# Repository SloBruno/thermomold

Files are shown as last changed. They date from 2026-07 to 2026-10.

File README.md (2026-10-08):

# ThermoMold

Monitoramento e controle remoto de um circuito de refrigeração de molde. O projeto combina um **ESP32 com sensores físicos**, um **backend Node.js no Render** e um **dashboard React publicado no GitHub Pages**. Também preserva o simulador didático de circuito de refrigeração já existente.

> **Estado atual:** o código suporta dois termopares MAX6675, nível AJ-SR04M, vazão ZJ-S201, duas bombas via relé HW-383 e telemetria em tempo quase real. A validação física do ZJ-S201 e dos relés com as bombas ainda deve ser feita em bancada antes de uso contínuo.

- Dashboard: <https://slobruno.github.io/thermomold/>
- Sensores físicos: <https://slobruno.github.io/thermomold/#/sensor-real>
- Calibração: <https://slobruno.github.io/thermomold/#/calibracao>
- Controle de bombas: <https://slobruno.github.io/thermomold/#/bombas>
- API: <https://thermomold.onrender.com/api/telemetry>

## Índice

- [Objetivo e escopo](#objetivo-e-escopo)
- [Arquitetura](#arquitetura)
- [Funcionalidades](#funcionalidades)
- [Hardware e ligações](#hardware-e-ligações)
- [Firmware ESP32](#firmware-esp32)
- [Backend e API](#backend-e-api)
- [Frontend](#frontend)
- [Implantação](#implantação)
- [Desenvolvimento local](#desenvolvimento-local)
- [Segurança e limites atuais](#segurança-e-limites-atuais)
- [Validação de bancada](#validação-de-bancada)
- [Próximas etapas](#próximas-etapas)

## Objetivo e escopo

O ThermoMold é um sistema para acompanhar um pequeno circuito hidráulico de refrigeração e permitir o acionamento remoto de duas bombas.

### Incluído no escopo atual

- Medição de temperatura em dois pontos com dois módulos MAX6675 e termopares tipo K.
- Calibração pública de dois pontos, independente para cada MAX6675, com revisão persistente.
- Medição de distância/nível com AJ-SR04M.
- Medição de vazão instantânea e volume acumulado com ZJ-S201.
- Telemetria do ESP32 para a internet por Wi-Fi e HTTPS.
- Dashboard web com atualização periódica e atualização em tempo real por Socket.IO.
- Comando manual de liga/desliga para duas bombas, por relé duplo HW-383.
- Estado seguro: bombas desligadas ao iniciar o ESP32, ao perder Wi-Fi ou ao perder comunicação válida com o backend.
- Portal de provisionamento Wi-Fi e armazenamento persistente da configuração do dispositivo no ESP32.
- Simulador de refrigeração e biblioteca de moldes, independentes da telemetria física.
- Esquema elétrico editável no KiCad, PDF e instruções de montagem em texto.

### Fora do escopo atual

- Controle de velocidade/intensidade das bombas. O HW-383 é relé mecânico e só permite liga/desliga; PWM exige driver MOSFET apropriado.
- Histórico persistente de medições. O backend mantém somente a última leitura em memória.
- Autenticação de operadores para o controle de bombas. O controle foi configurado como público nesta fase.
- Atualização OTA do firmware.
- Calibração física final do fator de pulsos do ZJ-S201.
- Proteções automáticas por nível baixo, falta de vazão, temperatura ou tempo máximo de bomba ligada.

## Arquitetura

```text
                         ┌───────────────────────────┐
                         │ GitHub Pages               │
                         │ React + Vite               │
                         │ Dashboard / Sensores /     │
                         │ Controle de Bombas         │
                         └─────────────┬─────────────┘
                                       │ HTTPS + Socket.IO
                                       │
                         ┌─────────────▼─────────────┐
                         │ Render                     │
                         │ Express + Socket.IO        │
                         │ - valida telemetria        │
                         │ - mantém última leitura    │
                         │ - mantém comando desejado  │
                         └─────────────┬─────────────┘
                                       │ HTTPS POST /api/telemetry
                                       │ resposta inclui comando das bombas
                                       │
                         ┌─────────────▼─────────────┐
                         │ ESP32                      │
                         │ Wi-Fi + LittleFS           │
                         │ Sensores + relés           │
                         └───┬────┬────┬────┬────┬────┘
                             │    │    │    │    │
                     MAX6675 #1  #2  AJ-SR04M ZJ-S201 HW-383
                             │    │    │    │      │
                       Termopar 1 2  Nível  Vazão  2 bombas
```

### Fluxo de telemetria e comando

1. O ESP32 mede os sensores e o estado real dos dois relés.
2. O ESP32 envia um `POST` HTTPS para `/api/telemetry`.
3. O backend valida a leitura, salva a última amostra em memória e a transmite ao site por Socket.IO.
4. O backend responde com o estado desejado das bombas.
5. O ESP32 aplica o comando nos GPIOs D19 e D33.
6. A telemetria seguinte informa o estado físico aplicado.

O ciclo normal de telemetria é de aproximadamente **500 ms**. A vazão é atualizada internamente em uma janela de um segundo.

### Fluxo de provisionamento do ESP32

Na primeira inicialização, ou após apagar a configuração, o ESP32 cria a rede `ThermoMold-Setup`:

1. Conecte um celular ou computador à rede de configuração.
2. Abra `http://192.168.4.1`.
3. Selecione a rede Wi-Fi 2,4 GHz e informe a senha.
4. Informe o endpoint HTTPS e a chave do dispositivo localmente.
5. Salve.

O WiFiManager grava as credenciais de Wi-Fi na flash. O firmware grava `deviceId`, endpoint, chave e intervalo em LittleFS, no arquivo local `/config.json`. Assim, o ESP32 deve reconectar automaticamente após reinício ou queda de energia; não é necessário digitar a chave de novo enquanto a memória não for apagada.

## Funcionalidades

| Área | Funcionalidade | Estado |
|---|---|---|
| Telemetria | Dois MAX6675 | Implementado e já observado fisicamente |
| Calibração | Dois pontos por MAX6675 | Implementado; requer validação com referências conhecidas |
| Telemetria | AJ-SR04M | Implementado e já observado fisicamente |
| Telemetria | ZJ-S201 | Implementado no código; requer calibração/validação física |
| Controle | Duas bombas por HW-383 | Implementado; requer teste elétrico de polaridade do relé |
| Segurança | Desliga bombas em boot, perda de Wi-Fi ou timeout | Implementado no firmware |
| Web | Tela de sensores reais | Implementado |
| Web | Tela manual de bombas | Implementado, pública e sem senha |
| Web | Simulador e biblioteca de moldes | Implementado |
| Persistência | Configuração Wi-Fi/chave no ESP32 | Implementado |
| Persistência | Histórico de telemetria | Não implementado |
| Alertas | Alarmes, notificações e intertravamentos | Não implementado |
| OTA | Atualização por Wi-Fi | Não implementado |

## Hardware e ligações

### Componentes

- ESP32 DevKit.
- Fonte AC-DC 5 V / 6 A.
- Buck step-down 5 V → 3,3 V.
- Dois módulos MAX6675 com termopar tipo K.
- AJ-SR04M.
- ZJ-S201.
- Módulo de relé duplo HW-383.
- Duas bombas de água de 3–6 V.
- Dois diodos 1N4007, um por bomba.
- Seis resistores de 10 kΩ: três para o divisor do AJ-SR04M e três para o divisor do ZJ-S201.

### Distribuição de energia

```text
Fonte +5 V ─┬─ buck IN+
            ├─ VCC do HW-383
            ├─ VCC do AJ-SR04M
            ├─ positivo do ZJ-S201
            └─ COM dos canais K1 e K2

Fonte GND ──┬─ buck IN− e buck OUT−
            ├─ GND do ESP32
            ├─ GND dos MAX6675
            ├─ GND do AJ-SR04M e ZJ-S201
            ├─ GND do HW-383
            └─ negativos das bombas

Buck +3,3 V ── ESP32 3V3 e VCC dos dois MAX6675
```

Ajuste o buck próximo de **3,3 V** antes de conectar o ESP32. Nunca passe de **3,6 V**. Use o pino `3V3` do ESP32; `VIN`, `VN` e `VP` não são entradas para essa alimentação. Não alimente simultaneamente por USB e pelo buck durante a operação normal.

### Tabela de pinos

| Função | ESP32 | Observação |
|---|---:|---|
| MAX6675 #1 SCK / CS / SO | D32 / D21 / D27 | Termopar 1 |
| MAX6675 #2 SCK / CS / SO | D18 / D23 / D22 | Termopar 2 |
| AJ-SR04M TRIG | D25 | Direto |
| AJ-SR04M ECHO | D26 | Via divisor 10 kΩ / 20 kΩ |
| ZJ-S201 sinal | D34 | Via divisor 10 kΩ / 20 kΩ |
| HW-383 IN1 | D19 | Bomba 1 / K1 |
| HW-383 IN2 | D33 | Bomba 2 / K2 |

Os sinais ECHO do AJ-SR04M e o sinal do ZJ-S201 podem ser de 5 V; não os conecte diretamente a um GPIO de 3,3 V.

```text
ECHO ou SINAL → 10k → ponto do GPIO
                           │
                           └→ 10k → 10k → GND
```

O divisor gera aproximadamente 3,33 V quando a entrada é exatamente 5 V.

### Bombas e relés

- K1: `COM` recebe +5 V; `NO` vai ao positivo da bomba 1; negativo da bomba 1 vai ao GND comum.
- K2: `COM` recebe +5 V; `NO` vai ao positivo da bomba 2; negativo da bomba 2 vai ao GND comum.
- `NC` permanece sem ligação nesta arquitetura.
- Cada bomba recebe um 1N4007 em paralelo: **faixa do diodo no positivo**, sem faixa no negativo/GND.

Consulte [`hardware/README.md`](hardware/README.md) para o procedimento detalhado de montagem. Os artefatos do esquema estão em [`hardware/`](hardware/): KiCad, PDF e PNG.

## Firmware ESP32

Pasta: [`firmware/`](firmware/)

Tecnologias principais:

- PlatformIO e Arduino para ESP32.
- `WiFiManager` para portal e credenciais Wi-Fi persistentes.
- `LittleFS` para a configuração local não-Wi-Fi.
- `HTTPClient` e `WiFiClientSecure` para envio de telemetria HTTPS.
- `ArduinoJson` para configuração e resposta de comandos.
- `MAX6675` para os termopares.
- Interrupção em D34 para contar os pulsos do ZJ-S201.

### Fail-safe das bombas

As saídas de relé são configuradas para desligado antes de abrir o portal Wi-Fi. Durante a execução:

- Se o Wi-Fi cair, ambas as bombas são desligadas.
- Se um comando válido do backend não chegar por 3 segundos, ambas as bombas são desligadas.
- Se a resposta de telemetria não trouxer comando de bombas válido, ambas as bombas permanecem desligadas.

O HW-383 pode ser ativo-alto ou ativo-baixo. O firmware está configurado inicialmente como ativo-alto por `kRelayActiveLevel = HIGH`. Faça o teste sem as bombas e inverta para `LOW` se os LEDs/relés ligarem ao iniciar.

### Vazão

A conversão inicial usa a constante de família YF/ZJ-S201:

```text
frequência de pulsos (Hz) = 7,5 × vazão (L/min)
```

Ela é um ponto de partida. Calibre com um volume conhecido e ajuste `kFlowPulsesPerLiterPerMinute` em [`firmware/include/actuators.h`](firmware/include/actuators.h) se o sensor físico divergir.

### Compilar, testar e gravar

```bash
cd firmware
platformio test -e native
platformio run -e esp32dev
platformio run -e esp32dev -t upload
platformio device monitor -b 115200
```

Leia também [`firmware/README.md`](firmware/README.md).

## Backend e API

Pasta: [`server/`](server/)

O backend usa Express, Socket.IO e TypeScript. Ele valida as leituras, mantém a última amostra, publica mudanças para o dashboard e armazena o comando de calibração em `calibration.json` (ou no caminho de `CALIBRATION_FILE`).

### Endpoints principais

| Método | Rota | Função |
|---|---|---|
| `GET` | `/health` | Health check do serviço |
| `GET` | `/api/telemetry` | Última telemetria e estado `online`, `stale` ou `offline` |
| `POST` | `/api/telemetry` | Recebe a telemetria autenticada do ESP32 |
| `GET` | `/api/pumps` | Estado desejado das duas bombas |
| `POST` | `/api/pumps` | Altera o estado desejado: `{"pump1":true}` ou `{"pump2":false}` |
| `GET` | `/api/calibration` | Lê a calibração pública atual e sua revisão |
| `POST` | `/api/calibration` | Salva dois pontos por sensor e incrementa a revisão |

### Contrato resumido de telemetria

```json
{
  "deviceId": "thermomold-abc123",
  "temperatureC": 25.5,
  "sensor": "MAX6675",
  "sensors": {
    "thermocouples": [
      { "id": "max6675-1", "rawTemperatureC": 25.2, "temperatureC": 25.5 },
      { "id": "max6675-2", "rawTemperatureC": 24.8, "temperatureC": 24.8 }
    ],
    "level": { "sensor": "AJ-SR04M", "distanceMm": 227 },
    "flow": { "sensor": "ZJ-S201", "litersPerMinute": 1.2, "totalLiters": 3.45 }
  },
  "pumps": { "pump1": false, "pump2": false }
}
```

A amostra também inclui `rawTemperatureC` (legado do sensor 1) e `calibrationRevision`; cada termopar inclui seu próprio `rawTemperatureC` e temperatura corrigida. A resposta autenticada do ESP32 inclui `commands.pumps` e `commands.calibration`. O ESP32 só aplica uma revisão maior que a gravada e persiste o comando em LittleFS.

### Calibração de dois pontos

Abra a tela pública **Calibração**, anote a leitura bruta de cada termopar em duas temperaturas de referência conhecidas e informe os quatro valores por sensor. A correção aplicada no ESP32 é linear, inclusive entre e fora dos pontos:

```text
temperaturaCorrigida = referenciaBaixa
  + (temperaturaBruta - brutaBaixa)
  * (referenciaAlta - referenciaBaixa) / (brutaAlta - brutaBaixa)
```

### Variáveis de ambiente do servidor

| Variável | Obrigatória em produção | Uso |
|---|---|---|
| `PORT` | Não | Porta HTTP; o Render define automaticamente |
| `CLIENT_ORIGIN` | Sim | Origem permitida do GitHub Pages, sem o caminho do repositório |
| `TELEMETRY_DEVICE_KEY` | Sim | Chave aceita em `X-Device-Key` nos envios do ESP32 |
| `TELEMETRY_STALE_MS` | Recomendado | Tempo sem leitura para marcar telemetria como desatualizada; padrão 30000 |
| `CALIBRATION_FILE` | Não | Arquivo de persistência do comando; padrão `calibration.json` no diretório do servidor |

Segredos devem existir apenas no painel do Render ou no portal local do ESP32. Nunca os coloque em commits, issues, chat ou arquivos rastreados.

## Frontend

Pasta: [`client/`](client/)

O dashboard é React + TypeScript + Vite e usa HashRouter, permitindo rotas estáticas no GitHub Pages.

Principais telas:

- **Simulador:** cenário de refrigeração e falhas simuladas.
- **Sensor Real:** temperaturas, distância de nível, vazão e estado confirmado das bombas.
- **Calibração:** wizard público para os dois pontos de cada MAX6675 e revisão atualmente salva.
- **Bombas:** comando manual e comparação entre o estado desejado e o último estado confirmado pelo ESP32.

O frontend consulta REST e recebe eventos Socket.IO. Há também atualização periódica para que a tela se recupere quando uma conexão de socket é interrompida.

## Implantação

### Backend: Render

[`render.yaml`](render.yaml) define o serviço Node.js na pasta `server/`:

```text
build: npm ci && npm run build
start: npm run start
```

No Render, configure pelo menos:

```text
CLIENT_ORIGIN=https://slobruno.github.io
TELEMETRY_DEVICE_KEY=[seu segredo local]
TELEMETRY_STALE_MS=30000
```

### Frontend: GitHub Pages

O workflow [`.github/workflows/deploy-pages.yml`](.github/workflows/deploy-pages.yml) roda a cada push em `main`.

Defina a variável de repositório GitHub:

```text
VITE_SOCKET_URL=https://thermomold.onrender.com
```

O workflow força `VITE_ROUTER_MODE=hash` e a base `/<nome-do-repositório>/`, então as rotas usam `#/...` corretamente no Pages.

### Ordem correta para uma atualização funcional

1. Testar firmware, servidor e cliente localmente.
2. Fazer commit e push para `main`.
3. Aguardar o deploy do GitHub Pages e do Render.
4. Gravar o firmware novo no ESP32, quando houver mudança de firmware.
5. Conferir `/api/telemetry` e o dashboard com o ESP ligado.

Publicar o código não atualiza o firmware que já está gravado no ESP32.

## Desenvolvimento local

Pré-requisitos:

- Node.js 20 ou superior.
- npm.
- PlatformIO para firmware.
- Python 3 para o ambiente do PlatformIO, quando necessário.

```bash
# Backend
cd server
npm ci
npm test
npm run build
npm run dev

# Em outro terminal: frontend
cd client
npm ci
npm run build
npm run dev

# Firmware
cd firmware
platformio test -e native
platformio run -e esp32dev
```

Endereços locais usuais:

- Frontend: `http://localhost:5173`
- Backend: `http://localhost:3001`

Use os arquivos `client/.env.example` e `server/.env.example` somente como modelos locais. Não crie arquivos com segredo dentro do repositório.

## Segurança e limites atuais

### Riscos conhecidos

1. **Controle de bombas é público.** A rota e a página não têm autenticação nesta fase. Quem tiver acesso ao site pode enviar comando de liga/desliga.
2. **Sem histórico persistente.** Leituras e estado desejado de bomba ficam em memória; uma reinicialização do Render remove os dados e reinicia as bombas desejadas como desligadas.
3. **TLS sem validação completa no ESP32.** O transporte usa HTTPS, mas o firmware usa `setInsecure()` enquanto não há sincronização de relógio/NTP e CA fixada. O tráfego é criptografado, porém a identidade do servidor não é validada pelo ESP32.
4. **Sem intertravamento por nível ou vazão.** O fail-safe de comunicação existe, mas o sistema ainda não recusa bomba com tanque vazio ou falta de fluxo.
5. **Divisores próximos ao limite.** A saída de aproximadamente 3,33 V é aceitável para fonte nominal de 5 V, mas perde margem se a fonte estiver acima disso. Meça antes de ligar ao ESP32.

### Medidas já implementadas

- Sem chaves em código ou no repositório.
- Cabeçalho `X-Device-Key` para autenticar telemetria no backend.
- Bombas desligadas por padrão em boot e por falha de comunicação.
- Validação de formato e faixa de cada leitura no backend.
- GPIOs de relé inicializados como desligados antes de qualquer operação de rede.

## Validação de bancada

Antes de conectar as bombas:

1. Ajuste e meça o buck em 3,3 V.
2. Confira todos os GNDs comuns.
3. Conecte o sistema sem as bombas nos bornes `NO`.
4. Energize o ESP32 pela fonte/buck e observe os LEDs do HW-383.
5. Os relés devem iniciar desligados. Se ligarem, ajuste `kRelayActiveLevel` e grave o firmware novamente.
6. Acione uma bomba por vez na página **Bombas** e confirme LED e clique do relé.
7. Meça a tensão no D26 e D34 com os sensores em nível alto; não pode ultrapassar 3,6 V.
8. Só então conecte as bombas e teste com água.
9. Meça um volume conhecido para calibrar o ZJ-S201.
10. Para calibrar temperatura, use duas referências estáveis por termopar, salve na tela **Calibração** e confirme no **Sensor Real** a revisão e os valores brutos/corrigidos.

Não use este sistema sem supervisão até concluir esses testes e adicionar os intertravamentos de nível e vazão.

## Próximas etapas

Ordem recomendada:

1. Validar eletricamente relés, bombas e ZJ-S201.
2. Implementar intertravamento: bloquear/desligar bomba por nível baixo e por vazão zero.
3. Adicionar limites de temperatura e alarmes visuais no site.
4. Criar persistência de séries históricas em banco de dados, com retenção e exportação CSV.
5. Proteger a página e API de bombas por autenticação e lista de operadores permitidos.
6. Implementar OTA com validação de integridade e rollback.
7. Criar bot de WhatsApp isolado para dúvidas técnicas, estado do equipamento e alertas — sem acesso direto ao computador ou a comandos irrestritos.

## Estrutura do repositório

```text
.
├── client/       # Dashboard React/Vite
├── server/       # API Express, Socket.IO e simulador
├── firmware/     # ESP32 / PlatformIO
├── hardware/     # KiCad, PDF, PNG e instruções de montagem
├── shared/       # Tipos compartilhados TypeScript
├── render.yaml   # Blueprint do Render
└── .github/      # Deploy do GitHub Pages
```

## Licença e operação

Este repositório é um projeto de engenharia em desenvolvimento. As ligações e comandos de bombas envolvem eletricidade, água e equipamento físico. Revise a montagem, use proteção adequada para a instalação final e mantenha supervisão humana durante os testes.

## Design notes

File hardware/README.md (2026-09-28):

# ThermoMold — Esquema elétrico

Arquivos nesta pasta:

- `thermomold.kicad_sch` / `thermomold.kicad_pro` — esquema editável no KiCad 7
- `thermomold.pdf` — versão para imprimir
- `thermomold.png` — prévia

> O esquema KiCad ainda não inclui o sensor de fluxo ZJ-S201. A ligação dele está descrita abaixo e é a referência válida.

## Componentes

- ESP32 DevKit
- Fonte AC-DC 5 V / 6 A
- Buck step-down ajustado para 3,3 V
- 2 módulos MAX6675 com termopar tipo K
- Sensor ultrassônico AJ-SR04M
- Sensor de fluxo ZJ-S201
- Módulo relé duplo HW-383
- 2 bombas de água 3–6 V
- 2 diodos 1N4007
- 6 resistores de 10 kΩ (3 para o AJ-SR04M, 3 para o ZJ-S201)

## Alimentação

A fonte entrega 5 V. Ligue o positivo da fonte na entrada positiva do buck, no VCC do módulo relé, no VCC do AJ-SR04M, no positivo do sensor de fluxo ZJ-S201 e nos pinos COM dos dois canais do relé.

Ligue o negativo da fonte no negativo de entrada do buck, no GND do ESP32, no GND dos dois módulos MAX6675, no GND do AJ-SR04M, no negativo do ZJ-S201, no GND do módulo relé e nos negativos das duas bombas. Esse é o GND comum de todo o sistema.

Ajuste o buck para 3,3 V antes de conectar o ESP32. Depois ligue a saída positiva de 3,3 V do buck no pino 3V3 do ESP32. Ligue o negativo da saída do buck no GND comum. Não ligue a saída de 3,3 V no VIN e não use os pinos VN ou VP como alimentação. Não alimente o ESP32 pelo USB ao mesmo tempo que pelo buck.

## Termopares (MAX6675)

No primeiro MAX6675, ligue VCC no 3,3 V do buck e GND no GND comum. Ligue SCK no D32, CS no D21 e SO no D27 do ESP32. O primeiro termopar entra nos bornes positivo e negativo desse MAX6675.

No segundo MAX6675, ligue VCC no 3,3 V do buck e GND no GND comum. Ligue SCK no D18, CS no D23 e SO no D22 do ESP32. O segundo termopar entra nos bornes positivo e negativo desse segundo MAX6675.

## Ultrassônico (AJ-SR04M)

Ligue VCC no 5 V da fonte e GND no GND comum. Ligue TRIG diretamente no D25 do ESP32.

O ECHO vai para o divisor de tensão antes de chegar ao D26. Ligue ECHO em um resistor de 10 kΩ. Na outra ponta desse resistor fica o ponto central. Esse ponto central vai para o D26 do ESP32. Desse mesmo ponto central, ligue mais dois resistores de 10 kΩ em série até o GND comum. Assim, o ECHO de 5 V chega ao ESP32 com aproximadamente 3,33 V.

```text
ECHO → 10k → ponto central → D26
                  │
                  └→ 10k → 10k → GND
```

## Sensor de fluxo (ZJ-S201)

Ligue o positivo no 5 V da fonte e o negativo no GND comum. O fio de sinal não vai direto ao ESP32. Ligue o sinal em um resistor de 10 kΩ. Na outra ponta desse resistor fica o ponto central. Esse ponto central vai para o D34 do ESP32. Desse mesmo ponto central, ligue mais dois resistores de 10 kΩ em série até o GND comum.

```text
SINAL → 10k → ponto central → D34
                   │
                   └→ 10k → 10k → GND
```

## Relé e bombas (HW-383)

No módulo relé, ligue VCC no 5 V da fonte e GND no GND comum. Ligue IN1 no D19 e IN2 no D33 do ESP32. K1 e K2 são os nomes dos dois relés na placa.

No canal K1, ligue o positivo de 5 V da fonte no borne COM. Ligue o borne NO no positivo da bomba 1. Ligue o negativo da bomba 1 no GND comum. Deixe NC sem ligação.

No canal K2, ligue o positivo de 5 V da fonte no borne COM. Ligue o borne NO no positivo da bomba 2. Ligue o negativo da bomba 2 no GND comum. Deixe NC sem ligação.

Em cada bomba, coloque um diodo 1N4007 em paralelo. O lado com a faixa vai no positivo da bomba, no mesmo fio que vem do NO do relé. O outro lado vai no negativo da bomba, no mesmo fio que vai para o GND comum.

## Tabela de pinos do ESP32

| Pino | Função |
|---|---|
| 3V3 | Entrada 3,3 V do buck |
| GND | GND comum |
| D32 / D21 / D27 | MAX6675 #1 — SCK / CS / SO |
| D18 / D23 / D22 | MAX6675 #2 — SCK / CS / SO |
| D25 | AJ-SR04M TRIG |
| D26 | AJ-SR04M ECHO (via divisor) |
| D34 | ZJ-S201 sinal (via divisor) |
| D19 | Relé IN1 → bomba 1 |
| D33 | Relé IN2 → bomba 2 |

## Comportamento do firmware

- As bombas começam desligadas ao ligar o ESP32.
- O site envia o comando pela página **Bombas**; o ESP32 aplica o comando em até ~0,5 s.
- Se o ESP32 perder o Wi-Fi ou ficar 3 s sem resposta do servidor, desliga as duas bombas.
- O controle de bombas no site é público (sem senha).

## Teste de bancada antes de ligar as bombas

1. Ligue tudo **sem as bombas** conectadas nos bornes NO.
2. Ao energizar, os LEDs dos relés devem ficar **apagados**. Se acenderem sozinhos, o seu HW-383 é ativo em nível baixo: troque `kRelayActiveLevel` para `LOW` em `firmware/src/main.cpp` e grave de novo.
3. Na página **Bombas**, clique em Ligar/Desligar e confira o clique e o LED de cada relé.
4. Só depois conecte as bombas.

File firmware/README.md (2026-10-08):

# ThermoMold ESP32 multi-sensor telemetry

PlatformIO/Arduino firmware for an ESP32 connected to two MAX6675 K-type thermocouple modules and one AJ-SR04M ultrasonic level sensor. It keeps the legacy fields and sends all readings in `sensors` to the configured `/api/telemetry` URL:

```json
{"deviceId":"press-01","temperatureC":123.45,"rawTemperatureC":122.9,"calibrationRevision":3,"sensor":"MAX6675","sensors":{"thermocouples":[{"id":"max6675-1","rawTemperatureC":122.9,"temperatureC":123.45},{"id":"max6675-2","rawTemperatureC":126.5,"temperatureC":126.5}],"level":{"sensor":"AJ-SR04M","distanceMm":350}}}
```

`observedAt` is intentionally omitted: the server assigns its observation time. The `X-Device-Key` request header is sent only when `deviceKey` is configured.

## Wiring defaults

| Sensor | Signal | ESP32 GPIO |
| --- | --- | ---: |
| MAX6675 #1 | SCK / CLK | 32 |
| MAX6675 #1 | CS | 21 |
| MAX6675 #1 | SO / DO | 27 |
| MAX6675 #2 | SCK / CLK | 18 |
| MAX6675 #2 | CS | 23 |
| MAX6675 #2 | SO / DO | 22 |
| AJ-SR04M (R19 open, pulse mode) | RX / TRIG | 25 (output) |
| AJ-SR04M (R19 open, pulse mode) | TX / ECHO | 26 (input) |
| All modules | VCC | 3.3V |
| All modules | GND | GND |

The MAX6675 buses are software SPI and are deliberately fixed to this wiring. The AJ-SR04M is triggered with a 10 µs pulse and its round-trip echo is converted to millimetres using 0.343 mm/µs. MAX6675 only measures non-negative Celsius temperatures.

## Build and upload

1. Install PlatformIO Core or PlatformIO IDE.
2. From this `firmware/` directory, build with `platformio run -e esp32dev`.
3. Connect the ESP32 over USB and upload with `platformio run -e esp32dev -t upload`.
4. Monitor startup/configuration logs with `platformio device monitor -b 115200`.

The board target is the generic `esp32dev`; set `upload_port` locally in `platformio.ini` or pass PlatformIO's upload-port option if auto-discovery does not find the board.

## First-time provisioning

On first boot, the ESP32 starts the `ThermoMold-Setup` captive portal. Connect to that access point, open the portal page, and enter:

- Wi-Fi network and password (stored by WiFiManager in ESP32 flash, never in this repository)
- `Device ID`
- `Telemetry endpoint`: `https://thermomold.onrender.com/api/telemetry` (HTTPS obrigatório)
- optional `Device key`
- report interval (shown for reference; firmware publishes every 500 ms)

After it joins Wi-Fi, these non-Wi-Fi values are stored in LittleFS at `/config.json`. To force portal configuration again, erase the ESP32 flash or use WiFiManager's reset operation from a local maintenance build.

### Optional local config file

For repeatable setup, copy `data/config.example.json` to `data/config.json`, fill it locally, then upload LittleFS data with `platformio run -e esp32dev -t uploadfs`. `data/config.json` is gitignored. Do not commit a real endpoint, device key, Wi-Fi credential, or local address.

## Runtime behavior

- Se um MAX6675 falhar ou produzir temperatura inválida, a amostra é descartada. AJ-SR04M indisponível não bloqueia a telemetria: ele aparece como indisponível, enquanto os termopares continuam sendo enviados.
- Wi-Fi reconnection is attempted every 10 seconds while disconnected.
- Failed non-2xx telemetry posts are retained and retried with exponential backoff from 2 to 60 seconds.
- A medição e publicação normais ocorrem a cada 500 ms.
- The device key is not sent at all when it is blank.
- The authenticated telemetry response can carry a newer two-point calibration command. The ESP32 rejects older revisions, applies linear correction independently, and persists the accepted points/revision in LittleFS `/config.json`.

## Temperature calibration

Use the public web wizard at `/calibracao`. For each MAX6675, record two stable raw readings against known reference temperatures. The firmware applies the linear two-point formula and publishes both `rawTemperatureC` and corrected `temperatureC`, plus `calibrationRevision`, in every full telemetry sample.

Run the host-side payload contract test with `platformio test -e native`.

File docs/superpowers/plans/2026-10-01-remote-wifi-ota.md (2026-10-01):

# Remote Wi-Fi OTA Implementation Plan

> **For agentic workers:** REQUIRED SUB-SKILL: Use superpowers:subagent-driven-development (recommended) or superpowers:executing-plans to implement this plan task-by-task. Steps use checkbox (`- [ ]`) syntax for tracking.

**Goal:** Allow an already-provisioned ThermoMold ESP32 to securely fetch and install a new firmware binary from the Render backend over the internet, without USB or Bluetooth.

**Architecture:** The repository carries a versioned ESP32 binary and SHA-256 manifest under `server/public/ota/`. Render serves the binary and returns the manifest only to a device authenticated with `X-Device-Key`. The ESP32 polls the manifest, verifies a TLS certificate and SHA-256 of the download, then installs only a newer version.

**Tech Stack:** ESP32 Arduino/PlatformIO, WiFiClientSecure, Update.h, ArduinoJson, Express/TypeScript, Node test runner, SHA-256.

**Spec:** `README.md` and this plan.

## Global Constraints

- OTA must work over the internet; it must not require the computer and ESP32 to share a LAN.
- OTA manifest requires the existing `X-Device-Key`; never commit or log the key.
- The ESP32 must validate the Render TLS certificate for OTA downloads.
- The ESP32 must verify the binary SHA-256 before installation.
- A device with an empty key, invalid manifest, stale clock, invalid certificate, hash mismatch, or failed download must keep its installed firmware.
- The first OTA-capable firmware still needs one USB upload; subsequent updates use Wi-Fi.
- Keep pumps fail-safe and inactive during all OTA paths.

---

### Task 1: Firmware version and manifest parser

**Files:**
- Create: `firmware/include/ota_update.h`
- Modify: `firmware/test/test_telemetry_contract/test_telemetry_contract.cpp`

**Interfaces:**
- Produces: `bool isNewerFirmwareVersion(const std::string&, const std::string&)`.
- Produces: `OtaManifest parseOtaManifest(const std::string&)` containing `valid`, `version`, `url`, and lowercase `sha256`.

- [ ] **Step 1: Write failing host tests** for newer semantic versions and a malformed/invalid-hash manifest.
- [ ] **Step 2: Run `platformio test -e native`** and confirm the new tests fail because `ota_update.h` is absent.
- [ ] **Step 3: Implement the parser and semantic version comparison** using ArduinoJson; reject non-HTTPS URLs and hashes other than 64 lowercase hexadecimal characters.
- [ ] **Step 4: Run `platformio test -e native`** and confirm all firmware tests pass.
- [ ] **Step 5: Commit the tested parser.**

### Task 2: Backend manifest and binary distribution

**Files:**
- Create: `server/public/ota/manifest.json`
- Modify: `server/src/index.ts`
- Modify: `server/test/telemetry.test.ts` or create `server/test/ota.test.ts`

**Interfaces:**
- `GET /api/ota/manifest` authenticates with `X-Device-Key` and returns `{version,url,sha256}`.
- `/ota/thermomold.bin` serves the immutable binary referenced by the manifest.

- [ ] **Step 1: Write a failing HTTP-level test** asserting missing/wrong device key returns 401 and the correct key returns the manifest.
- [ ] **Step 2: Run the server test** and confirm it fails because no OTA route exists.
- [ ] **Step 3: Implement static binary serving plus authenticated manifest route**; never return the device key.
- [ ] **Step 4: Run all server tests and build.**
- [ ] **Step 5: Commit backend OTA distribution.**

### Task 3: Secure remote update in ESP32 runtime

**Files:**
- Modify: `firmware/src/main.cpp`
- Modify: `firmware/platformio.ini`
- Modify: `firmware/include/ota_update.h`
- Modify: `firmware/test/test_telemetry_contract/test_telemetry_contract.cpp`

**Interfaces:**
- `checkForOtaUpdate()` runs no more often than every 15 minutes after Wi-Fi and config are ready.
- It reads the authenticated manifest, compares version, downloads over TLS, validates SHA-256 and calls `Update.end()` only on success.

- [ ] **Step 1: Add a failing pure-function test** for rejecting a non-newer version.
- [ ] **Step 2: Implement the runtime OTA state machine** with NTP clock synchronization, pinned CA, 15-minute polling and serial-only status messages.
- [ ] **Step 3: Run native tests and `platformio run -e esp32dev`.**
- [ ] **Step 4: Commit the runtime OTA client.**

### Task 4: Package and activate the initial OTA image

**Files:**
- Create: `server/public/ota/thermomold.bin`
- Update: `server/public/ota/manifest.json`
- Modify: `README.md`
- Modify: `firmware/README.md`

**Interfaces:**
- Manifest version equals the firmware build version.
- SHA-256 equals the exact tracked binary.

- [ ] **Step 1: Build the firmware with an explicit release version.**
- [ ] **Step 2: Calculate SHA-256 and create the manifest.**
- [ ] **Step 3: Add README operation instructions and document the one-time USB bootstrap.**
- [ ] **Step 4: Verify manifest hash against the binary, run all tests/builds and `git diff --check`.**
- [ ] **Step 5: Commit, push, wait for Render deployment, then USB-upload the OTA-capable bootstrap firmware.**

### Task 5: Physical verification

**Files:** none beyond logs.

- [ ] **Step 1: Observe serial logs for Wi-Fi connection and OTA manifest check.**
- [ ] **Step 2: Verify the deployed `GET /api/ota/manifest` rejects unauthenticated requests.**
- [ ] **Step 3: Confirm normal telemetry continues after the OTA-capable firmware starts.**

## Self-review

- The plan covers remote reachability, authentication, certificate validation, hash verification, version comparison, deployment assets, USB bootstrap, and physical read-back.
- All security-sensitive inputs remain in Render/ESP local storage and are not added to source control.
- The binary is only installed after validated HTTPS metadata and a matching SHA-256 digest.

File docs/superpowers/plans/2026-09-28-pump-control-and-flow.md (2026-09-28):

# Pump Control and Flow Sensor Implementation Plan

> **For agentic workers:** REQUIRED SUB-SKILL: Use superpowers:executing-plans to implement this plan task-by-task. Steps use checkbox (`- [ ]`) syntax for tracking.

**Goal:** Manual on/off control of two pumps (HW-383 relays) from the public site, plus ZJ-S201 flow telemetry, with fail-safe pump shutdown on the ESP32.

**Architecture:** The site POSTs the desired pump state to the Render backend (`/api/pumps`). The backend keeps the desired state in memory (default: both off) and returns it in the response to every ESP32 telemetry POST. The ESP32 applies it on GPIO19/GPIO33, reports the actual relay state and the flow reading in the next telemetry, and turns both pumps off if it has no successful backend response for 3 s, loses Wi-Fi, or reboots.

**Tech Stack:** ESP32 Arduino (PlatformIO, Unity native tests), Express + Socket.IO (node:test), React + Vite.

**Spec:** Design approved in chat on 2026-09-28 (manual on/off only, no PWM, public control without password, fail-safe = off).

## Global Constraints

- Pump 1 = relay IN1 = GPIO19; Pump 2 = relay IN2 = GPIO33.
- Flow sensor ZJ-S201 signal = GPIO34 through a 10 kΩ / 20 kΩ divider.
- Relay logic is active-high by default and configurable by one constant (`kRelayActiveLevel`).
- Pumps default OFF on backend start and ESP32 boot.
- ESP32 command timeout: 3000 ms without a successful telemetry response → both pumps OFF.
- Telemetry interval stays 500 ms.
- Flow conversion: `L/min = pulses_per_second / 7.5` (YF-S201-family constant); the constant is named so it can be calibrated.
- Backward compatible: telemetry without `sensors.flow` or `pumps` is still accepted.
- No secrets in the repository.

## File Structure

- `server/src/pumps.ts` (new): pump desired-state store and validation.
- `server/src/telemetry.ts`: accept optional `sensors.flow` and `pumps`.
- `server/src/index.ts`: `GET/POST /api/pumps`, commands in telemetry response, Socket.IO broadcast.
- `server/test/pumps.test.ts` (new), `server/test/telemetry.test.ts`.
- `firmware/include/actuators.h` (new): pure helpers (flow conversion, fail-safe timeout, command parsing).
- `firmware/include/telemetry_contract.h`: payload builder with flow and pump state.
- `firmware/src/main.cpp`: relay outputs, flow ISR, command handling.
- `client/src/pages/PumpControlPage.tsx` (new), `client/src/App.tsx`, `client/src/pages/RealSensorPage.tsx`.
- `hardware/README.md` (new): wiring text + KiCad files.

### Task 1: Backend pump store and API
- [ ] Test: store starts `{pump1:false,pump2:false}`; `set` accepts booleans and rejects non-booleans/unknown keys.
- [ ] Implement `createPumpStore()` with `get()` and `set(input)`.
- [ ] Wire `GET/POST /api/pumps`; include `commands.pumps` in the `POST /api/telemetry` response; emit `pumps:data`.

### Task 2: Backend telemetry accepts flow and actual pump state
- [ ] Test: payload with `sensors.flow {sensor:'ZJ-S201', litersPerMinute, totalLiters}` and `pumps {pump1,pump2}` normalizes; negative flow rejected.
- [ ] Implement in `normalizeTelemetry`.

### Task 3: Firmware pure helpers
- [ ] Test: `flowLitersPerMinute(15 pulses, 1000 ms) == 2.0`; zero interval → 0.
- [ ] Test: `pumpsCommandExpired(last, now, 3000)`.
- [ ] Test: `parsePumpCommand` reads `"pump1":true,"pump2":false` from the response body; missing/garbled → both off.
- [ ] Test: payload builder appends `flow` and `pumps`.

### Task 4: Firmware integration
- [ ] Relay pins configured as outputs at inactive level before Wi-Fi provisioning.
- [ ] Flow ISR on GPIO34 (FALLING), window-based L/min, cumulative liters.
- [ ] Apply command after each successful POST; fail-safe off on timeout or Wi-Fi loss.
- [ ] Build `esp32dev`.

### Task 5: Site
- [ ] `PumpControlPage`: two cards with desired state, confirmed state from telemetry, Ligar/Desligar buttons.
- [ ] Nav entry "Bombas"; Sensor Real shows flow (L/min, total L).
- [ ] `npm run build`.

### Task 6: Hardware README
- [ ] `hardware/README.md` with the approved wiring text and links to the KiCad/PDF/PNG files.

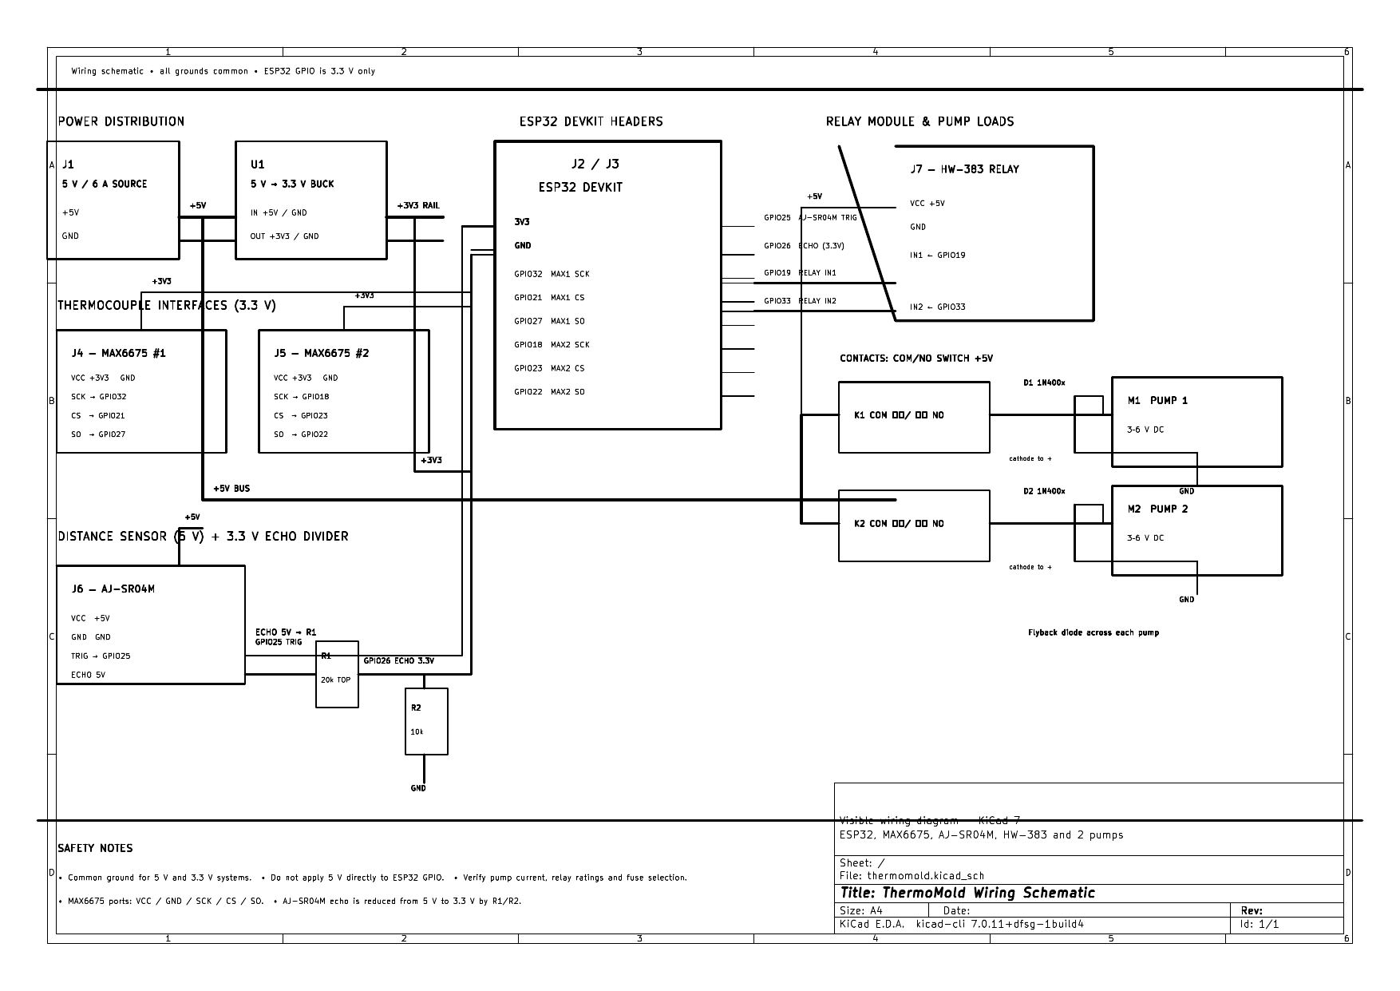
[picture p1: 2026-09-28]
hardware/thermomold.png

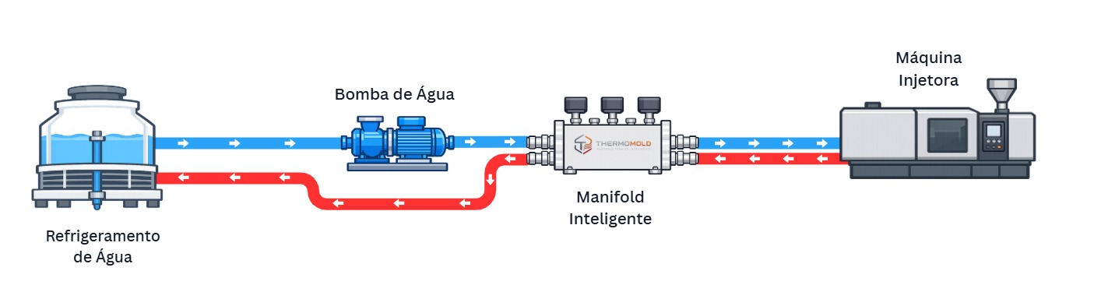
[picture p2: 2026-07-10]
client/src/imgs/bkg_simple.jpeg

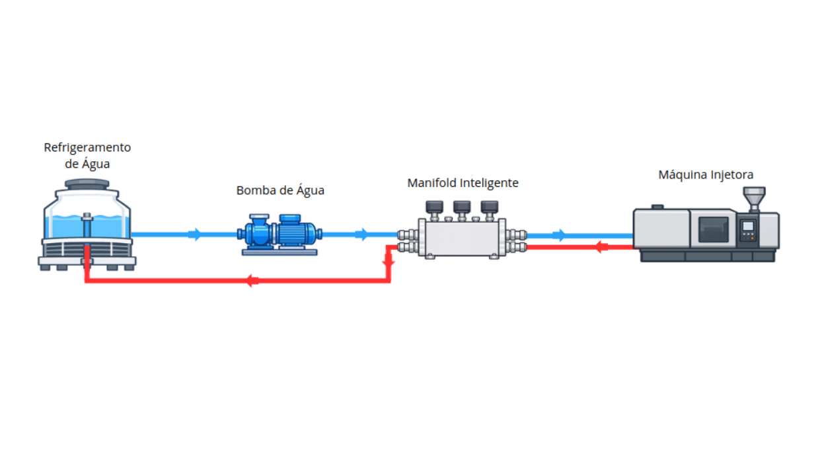
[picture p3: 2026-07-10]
client/src/imgs/simple_simulator_bkg.png

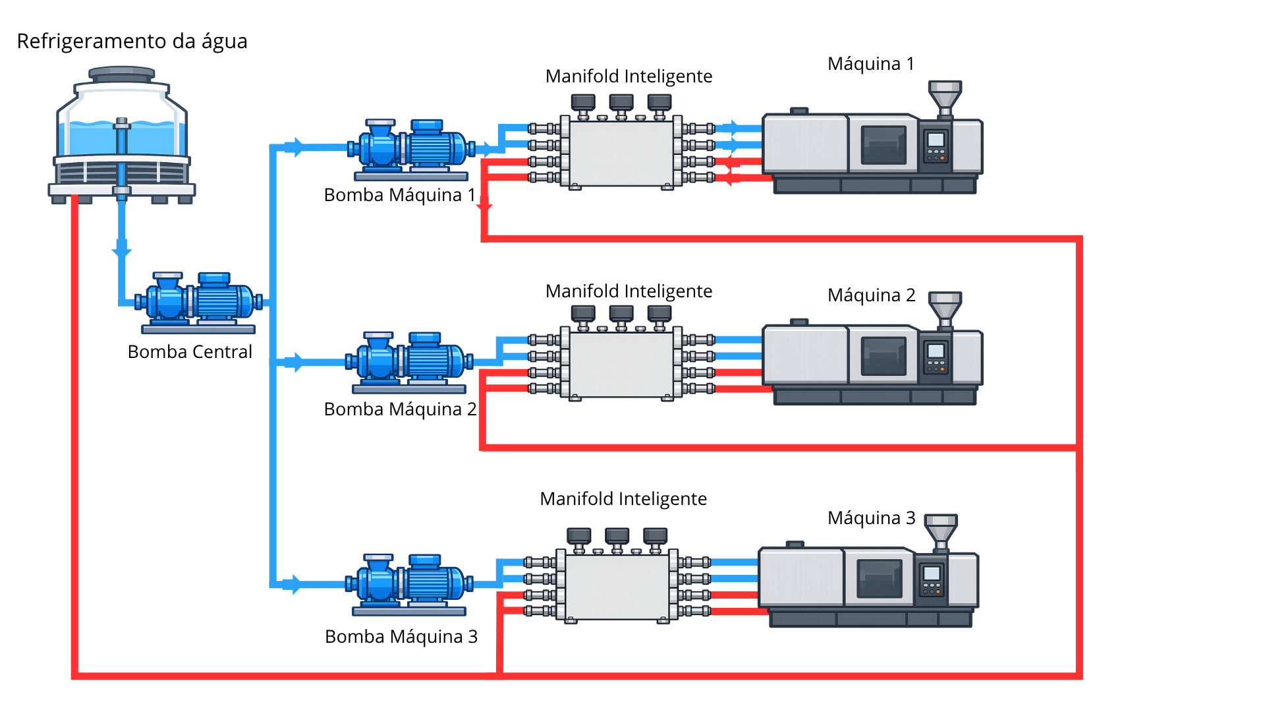
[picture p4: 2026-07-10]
client/src/imgs/simulator_bkg.png

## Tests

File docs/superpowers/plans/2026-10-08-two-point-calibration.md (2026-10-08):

# Two-Point MAX6675 Calibration Implementation Plan

> **For agentic workers:** REQUIRED SUB-SKILL: Use superpowers:subagent-driven-development (recommended) or superpowers:executing-plans to implement this plan task-by-task. Steps use checkbox (`- [ ]`) syntax for tracking.

**Goal:** Add public two-point calibration for both MAX6675 sensors, persist and revise the server command, deliver authenticated commands to the ESP32, persist them in LittleFS, and publish raw/corrected telemetry with a public calibration wizard.

**Architecture:** A shared calibration contract defines two points per sensor and a linear correction function. The server owns the public calibration command and revision, persists it in a small JSON file, validates updates, and includes the current command only in authenticated telemetry responses. The firmware stores the highest accepted revision in its existing LittleFS config, applies correction locally, and sends raw/corrected values plus revision. The client consumes the public GET/POST calibration API through a wizard route.

**Tech Stack:** Node.js/TypeScript, Express, Node test runner, React/Vite/Tailwind, Arduino ESP32/ArduinoJson/LittleFS, PlatformIO Unity native tests.

**Spec:** Approved two-point calibration requirements from the user task.

## Global Constraints

- Both MAX6675 sensors are calibrated independently with two reference points.
- A calibration command is public to read/update but is delivered to the ESP32 only after authenticated telemetry.
- Server revisions are monotonic and the ESP32 never applies an older revision.
- Device configuration remains in LittleFS `/config.json`.
- Telemetry preserves raw readings and includes corrected readings and applied calibration revision.
- Existing legacy telemetry fields and pump/level/flow behavior remain backward compatible.
- No destructive changes to existing user worktree changes; no push; commit locally.

### Task 1: Define and validate the calibration contract

**Files:**
- Create: `server/src/calibration.ts`
- Test: `server/test/calibration.test.ts`
- Modify: `server/src/telemetry.ts`, `server/test/telemetry.test.ts`

- [ ] Write failing tests for two-point validation, linear interpolation/extrapolation, monotonic revisions, persisted server state, and telemetry raw/corrected/revision normalization.
- [ ] Run `npm test -- --test-name-pattern calibration` from `server/` and confirm expected failures.
- [ ] Implement the smallest typed calibration store and telemetry normalization changes.
- [ ] Run the focused tests and then the complete server test suite.

### Task 2: Add authenticated server command delivery and public API

**Files:**
- Modify: `server/src/index.ts`
- Test: `server/test/calibration-api.test.ts`
- Modify: `server/.env.example`

- [ ] Write failing route tests for public GET/POST calibration, validation errors, revision increments, authenticated command delivery, and rejection of unauthenticated telemetry.
- [ ] Run the focused route tests and confirm failures.
- [ ] Implement file-backed calibration command persistence, `GET/POST /api/calibration`, and `commands.calibration` in authenticated telemetry responses only.
- [ ] Run the complete server test suite.

### Task 3: Implement firmware calibration persistence and corrected telemetry

**Files:**
- Modify: `firmware/include/actuators.h` or create `firmware/include/calibration.h`
- Modify: `firmware/include/telemetry_contract.h`
- Modify: `firmware/src/main.cpp`
- Modify: `firmware/test/test_telemetry_contract/test_telemetry_contract.cpp`
- Modify: `firmware/data/config.example.json`

- [ ] Write failing native tests for linear correction, invalid/older command rejection, persisted command serialization, and raw/corrected/revision payload shape.
- [ ] Run `pio test -e native` and confirm failures.
- [ ] Implement calibration helpers, LittleFS load/save, authenticated response parsing/application, and corrected telemetry generation.
- [ ] Run native firmware tests and the firmware build.

### Task 4: Build the public calibration wizard

**Files:**
- Create: `client/src/pages/CalibrationPage.tsx`
- Modify: `client/src/App.tsx`, `client/src/pages/RealSensorPage.tsx`
- Test: `client/src/pages/CalibrationPage.test.tsx` or repository-compatible client tests

- [ ] Add failing client tests for loading both sensors, entering two reference points, validation, submit, revision display, and raw/corrected preview.
- [ ] Run the client test command and confirm failures.
- [ ] Implement the public wizard and link it from navigation; show current raw/corrected values and revision on the real sensor page.
- [ ] Run client typecheck/build and the focused client tests.

### Task 5: Document, verify, and commit

**Files:**
- Modify: `README.md`, `firmware/README.md`

- [ ] Document the calibration formula, public wizard/API, authenticated delivery, LittleFS persistence, revision behavior, telemetry fields, and bench procedure.
- [ ] Run all server tests, client build, firmware native tests, firmware build, and inspect the final diff.
- [ ] Commit locally with `feat: add public two-point MAX6675 calibration`.

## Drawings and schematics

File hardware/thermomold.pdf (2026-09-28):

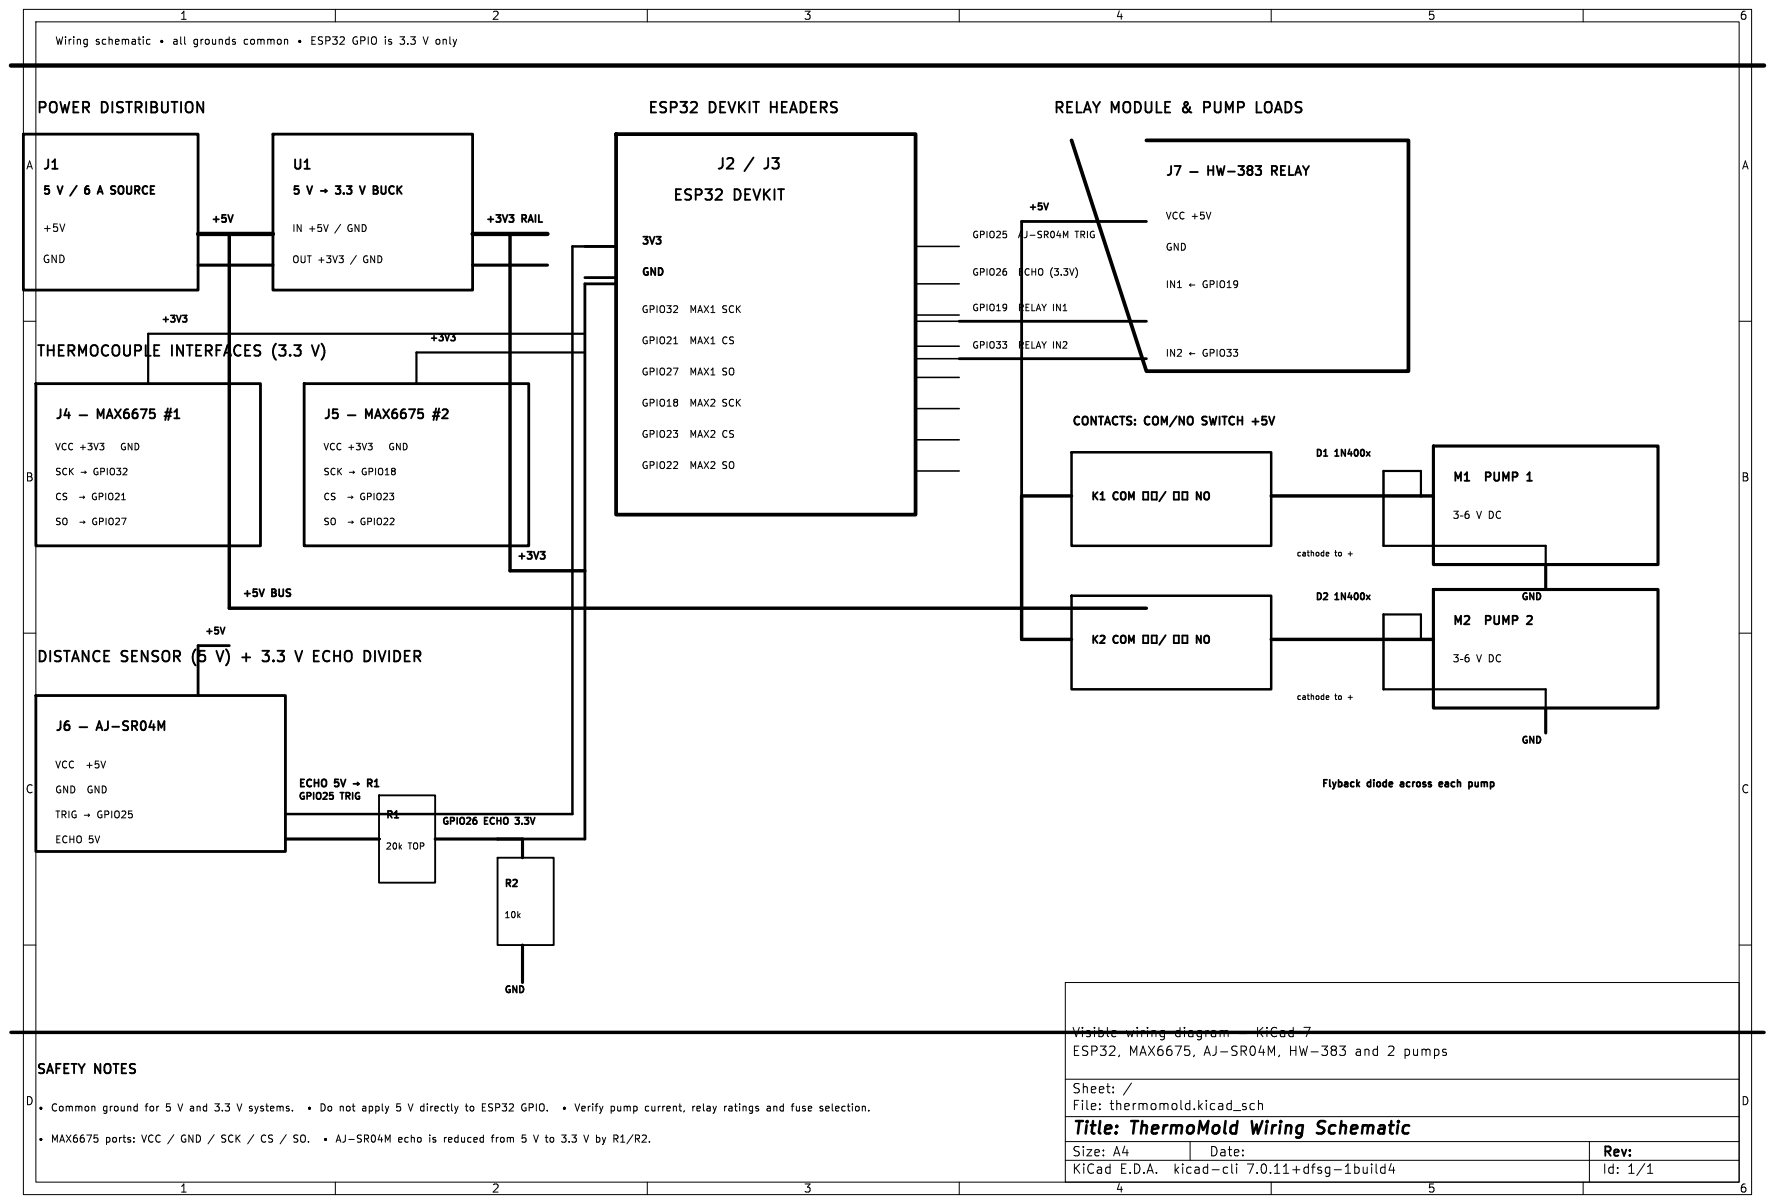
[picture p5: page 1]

K1 COM þÿ%%/ þÿ%% NO

Flyback diode across each pump

TRIG þÿ!’GPIO25 GND GND

Id: 1/1 Title: ThermoMold Wiring Schematic

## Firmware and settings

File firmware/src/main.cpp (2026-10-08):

#include <Arduino.h>
#include <ArduinoJson.h>
#include <HTTPClient.h>
#include <LittleFS.h>
#include <Update.h>
#include <MAX6675.h>
#include <WiFi.h>
#include <WiFiClient.h>
#include <WiFiClientSecure.h>
#include <WiFiManager.h>
#include <cmath>
#include <ctime>
#include <mbedtls/sha256.h>

#include "actuators.h"
#include "calibration.h"
#include "ota_update.h"
#include "sensor_readings.h"
#include "telemetry_contract.h"

namespace {
constexpr uint8_t kThermocoupleOneSckPin = 32;
constexpr uint8_t kThermocoupleOneCsPin = 21;
constexpr uint8_t kThermocoupleOneSoPin = 27;
constexpr uint8_t kThermocoupleTwoSckPin = 18;
constexpr uint8_t kThermocoupleTwoCsPin = 23;
constexpr uint8_t kThermocoupleTwoSoPin = 22;
constexpr uint8_t kLevelTriggerPin = 25;
constexpr uint8_t kLevelEchoPin = 26;
constexpr uint8_t kPump1RelayPin = 19;  // HW-383 IN1
constexpr uint8_t kPump2RelayPin = 33;  // HW-383 IN2
constexpr uint8_t kFlowSensorPin = 34;  // ZJ-S201 signal via 10k/20k divider
// HW-383 variants exist as active-high or active-low; flip this if a relay
// clicks ON at boot or the LEDs are inverted during the bench test.
constexpr uint8_t kRelayActiveLevel = HIGH;
constexpr unsigned long kLevelEchoTimeoutUs = 30000;
constexpr unsigned long kDefaultReportIntervalMs = 500;
constexpr unsigned long kReconnectIntervalMs = 10000;
constexpr unsigned long kInitialRetryDelayMs = 2000;
constexpr unsigned long kMaximumRetryDelayMs = 60000;
constexpr char kConfigPath[] = "/config.json";
constexpr char kOtaManifestUrl[] = "https://thermomold.onrender.com/api/ota/manifest";
constexpr unsigned long kOtaCheckIntervalMs = 15UL * 60UL * 1000UL;
constexpr time_t kEarliestValidTime = 1704067200;  // 2024-01-01 UTC
#ifndef THERMOMOLD_FIRMWARE_VERSION
#define THERMOMOLD_FIRMWARE_VERSION "0.1.0"
#endif

// GTS Root R4 anchors the current Render chain (WE1 -> GTS Root R4).
// OTA clients deliberately use this CA instead of setInsecure().
constexpr char kOtaRootCa[] = R"PEM(-----BEGIN CERTIFICATE-----
MIICCTCCAY6gAwIBAgINAgPlwGjvYxqccpBQUjAKBggqhkjOPQQDAzBHMQswCQYD
VQQGEwJVUzEiMCAGA1UEChMZR29vZ2xlIFRydXN0IFNlcnZpY2VzIExMQzEUMBIG
A1UEAxMLR1RTIFJvb3QgUjQwHhcNMTYwNjIyMDAwMDAwWhcNMzYwNjIyMDAwMDAw
WjBHMQswCQYDVQQGEwJVUzEiMCAGA1UEChMZR29vZ2xlIFRydXN0IFNlcnZpY2Vz
IExMQzEUMBIGA1UEAxMLR1RTIFJvb3QgUjQwdjAQBgcqhkjOPQIBBgUrgQQAIgNi
AATzdHOnaItgrkO4NcWBMHtLSZ37wWHO5t5GvWvVYRg1rkDdc/eJkTBa6zzuhXyi
QHY7qca4R9gq55KRanPpsXI5nymfopjTX15YhmUPoYRlBtHci8nHc8iMai/lxKvR
HYqjQjBAMA4GA1UdDwEB/wQEAwIBhjAPBgNVHRMBAf8EBTADAQH/MB0GA1UdDgQW
BBSATNbrdP9JNqPV2Py1PsVq8JQdjDAKBggqhkjOPQQDAwNpADBmAjEA6ED/g94D
9J+uHXqnLrmvT/aDHQ4thQEd0dlq7A/Cr8deVl5c1RxYIigL9zC2L7F8AjEA8GE8
p/SgguMh1YQdc4acLa/KNJvxn7kjNuK8YAOdgLOaVsjh4rsUecrNIdSUtUlD
-----END CERTIFICATE-----
)PEM";


struct DeviceConfig {
  String deviceId;
  String endpoint;
  String deviceKey;
  unsigned long reportIntervalMs = kDefaultReportIntervalMs;
};

DeviceConfig config;
CalibrationCommand calibration;
MAX6675 *thermocoupleOne = nullptr;
MAX6675 *thermocoupleTwo = nullptr;
WiFiManager wifiManager;
String pendingPayload;
unsigned long nextReportAt = 0;
unsigned long nextRetryAt = 0;
unsigned long retryDelayMs = kInitialRetryDelayMs;
unsigned long lastReconnectAttemptAt = 0;
unsigned long nextOtaCheckAt = 0;

bool pump1On = false;
bool pump2On = false;
uint32_t lastPumpCommandAt = 0;
bool hasPumpCommand = false;

volatile uint32_t flowPulseCount = 0;
uint32_t flowTotalPulses = 0;
uint32_t flowWindowStartedAt = 0;
float flowLpm = 0.0f;

void initializeCalibration() {
  calibration.valid = true;
  calibration.revision = 0;
  calibration.sensorOne = {{0.0f, 0.0f}, {100.0f, 100.0f}};
  calibration.sensorTwo = {{0.0f, 0.0f}, {100.0f, 100.0f}};
}

void IRAM_ATTR onFlowPulse() {
  flowPulseCount = flowPulseCount + 1;
}

uint8_t relayLevel(bool on) {
  return on ? kRelayActiveLevel : (kRelayActiveLevel == HIGH ? LOW : HIGH);
}

void applyPumps(bool nextPump1, bool nextPump2) {
  if (nextPump1 != pump1On || nextPump2 != pump2On) {
    Serial.printf("Pumps -> pump1=%s pump2=%s\n", nextPump1 ? "ON" : "OFF",
                  nextPump2 ? "ON" : "OFF");
  }
  pump1On = nextPump1;
  pump2On = nextPump2;
  digitalWrite(kPump1RelayPin, relayLevel(pump1On));
  digitalWrite(kPump2RelayPin, relayLevel(pump2On));
}

// Called first in setup(): relays must be inactive before the Wi-Fi portal,
// which can block for up to 3 minutes.
void configurePumpsOff() {
  digitalWrite(kPump1RelayPin, relayLevel(false));
  digitalWrite(kPump2RelayPin, relayLevel(false));
  pinMode(kPump1RelayPin, OUTPUT);
  pinMode(kPump2RelayPin, OUTPUT);
  applyPumps(false, false);
}

void enforcePumpFailSafe() {
  if (!pump1On && !pump2On) return;
  const bool wifiLost = WiFi.status() != WL_CONNECTED;
  const bool expired = !hasPumpCommand ||
                       pumpCommandExpired(lastPumpCommandAt, millis(), kPumpCommandTimeoutMs);
  if (wifiLost || expired) {
    Serial.println(wifiLost ? "Wi-Fi lost; pumps OFF (fail-safe)."
                            : "No backend command for 3 s; pumps OFF (fail-safe).");
    applyPumps(false, false);
  }
}

void updateFlow() {
  const uint32_t now = millis();
  const uint32_t windowMs = now - flowWindowStartedAt;
  if (windowMs < 1000) return;
  noInterrupts();
  const uint32_t pulses = flowPulseCount;
  flowPulseCount = 0;
  interrupts();
  flowTotalPulses += pulses;
  flowLpm = flowLitersPerMinute(pulses, windowMs);
  flowWindowStartedAt = now;
}

String defaultDeviceId() {
  return "thermomold-" + String(static_cast<uint32_t>(ESP.getEfuseMac()), HEX);
}

bool readSensorCalibration(JsonVariantConst source, SensorCalibration &target) {
  if (source.isNull() || source["low"].isNull() || source["high"].isNull()
      || source["low"]["rawC"].isNull() || source["low"]["referenceC"].isNull()
      || source["high"]["rawC"].isNull() || source["high"]["referenceC"].isNull()) return false;
  target.low.rawC = source["low"]["rawC"] | target.low.rawC;
  target.low.referenceC = source["low"]["referenceC"] | target.low.referenceC;
  target.high.rawC = source["high"]["rawC"] | target.high.rawC;
  target.high.referenceC = source["high"]["referenceC"] | target.high.referenceC;
  return isfinite(target.low.rawC) && isfinite(target.low.referenceC) &&
         isfinite(target.high.rawC) && isfinite(target.high.referenceC) &&
         target.low.rawC != target.high.rawC;
}

void loadConfig() {
  config.deviceId = defaultDeviceId();
  config.endpoint = defaultTelemetryEndpoint().c_str();
  if (!LittleFS.exists(kConfigPath)) return;

  File file = LittleFS.open(kConfigPath, "r");
  if (!file) return;
  JsonDocument document;
  const DeserializationError error = deserializeJson(document, file);
  file.close();
  if (error) {
    Serial.printf("Ignoring invalid %s: %s\n", kConfigPath, error.c_str());
    return;
  }

  config.deviceId = document["deviceId"] | config.deviceId;
  const char *configuredEndpoint = document["endpoint"] | "";
  if (configuredEndpoint[0] != '\0') config.endpoint = configuredEndpoint;
  config.deviceKey = document["deviceKey"] | "";
  const unsigned long interval = document["reportIntervalMs"] | kDefaultReportIntervalMs;
  if (interval >= 1000) config.reportIntervalMs = interval;
  const JsonVariantConst calibrationDocument = document["calibration"];
  const uint32_t revision = calibrationDocument["revision"] | 0U;
  SensorCalibration sensorOne = calibration.sensorOne;
  SensorCalibration sensorTwo = calibration.sensorTwo;
  if (readSensorCalibration(calibrationDocument["sensors"]["max6675-1"], sensorOne) &&
      readSensorCalibration(calibrationDocument["sensors"]["max6675-2"], sensorTwo)) {
    calibration.revision = revision;
    calibration.sensorOne = sensorOne;
    calibration.sensorTwo = sensorTwo;
  }
}

bool saveConfig() {
  File file = LittleFS.open(kConfigPath, "w");
  if (!file) return false;
  JsonDocument document;
  document["deviceId"] = config.deviceId;
  document["endpoint"] = config.endpoint;
  document["deviceKey"] = config.deviceKey;
  document["reportIntervalMs"] = config.reportIntervalMs;
  document["calibration"]["revision"] = calibration.revision;
  document["calibration"]["sensors"]["max6675-1"]["low"]["rawC"] = calibration.sensorOne.low.rawC;
  document["calibration"]["sensors"]["max6675-1"]["low"]["referenceC"] = calibration.sensorOne.low.referenceC;
  document["calibration"]["sensors"]["max6675-1"]["high"]["rawC"] = calibration.sensorOne.high.rawC;
  document["calibration"]["sensors"]["max6675-1"]["high"]["referenceC"] = calibration.sensorOne.high.referenceC;
  document["calibration"]["sensors"]["max6675-2"]["low"]["rawC"] = calibration.sensorTwo.low.rawC;
  document["calibration"]["sensors"]["max6675-2"]["low"]["referenceC"] = calibration.sensorTwo.low.referenceC;
  document["calibration"]["sensors"]["max6675-2"]["high"]["rawC"] = calibration.sensorTwo.high.rawC;
  document["calibration"]["sensors"]["max6675-2"]["high"]["referenceC"] = calibration.sensorTwo.high.referenceC;
  const bool saved = serializeJson(document, file) > 0;
  file.close();
  return saved;
}

void applyCalibrationCommand(const String &body) {
  JsonDocument document;
  if (deserializeJson(document, body)) return;
  const JsonVariantConst source = document["commands"]["calibration"];
  const uint32_t revision = source["revision"] | 0U;
  if (!calibrationRevisionIsNewer(calibration.revision, revision)) return;

  CalibrationCommand candidate = calibration;
  candidate.revision = revision;
  if (!readSensorCalibration(source["sensors"]["max6675-1"], candidate.sensorOne) ||
      !readSensorCalibration(source["sensors"]["max6675-2"], candidate.sensorTwo)) return;
  candidate.valid = true;
  calibration = candidate;
  if (!saveConfig()) Serial.println("Could not persist MAX6675 calibration.");
}

void provisionWiFiAndSettings() {
  char deviceId[64], endpoint[160], deviceKey[128], interval[12];
  config.deviceId.toCharArray(deviceId, sizeof(deviceId));
  config.endpoint.toCharArray(endpoint, sizeof(endpoint));
  config.deviceKey.toCharArray(deviceKey, sizeof(deviceKey));
  snprintf(interval, sizeof(interval), "%lu", config.reportIntervalMs);

  WiFiManagerParameter deviceIdField("deviceId", "Device ID", deviceId, sizeof(deviceId));
  WiFiManagerParameter endpointField("endpoint", "Telemetry endpoint", endpoint, sizeof(endpoint));
  WiFiManagerParameter deviceKeyField("deviceKey", "Device key (optional)", deviceKey, sizeof(deviceKey));
  WiFiManagerParameter intervalField("reportIntervalMs", "Report interval ms", interval, sizeof(interval));
  wifiManager.addParameter(&deviceIdField);
  wifiManager.addParameter(&endpointField);
  wifiManager.addParameter(&deviceKeyField);
  wifiManager.addParameter(&intervalField);
  wifiManager.setConfigPortalTimeout(180);

  if (!wifiManager.autoConnect("ThermoMold-Setup")) {
    Serial.println("Wi-Fi provisioning timed out; rebooting.");
    ESP.restart();
  }

  config.deviceId = deviceIdField.getValue();
  config.endpoint = endpointField.getValue();
  config.deviceKey = deviceKeyField.getValue();
  const unsigned long requestedInterval = String(intervalField.getValue()).toInt();
  if (requestedInterval >= 1000) config.reportIntervalMs = requestedInterval;
  if (!saveConfig()) Serial.println("Could not save device configuration.");
}

void configureSensor() {
  thermocoupleOne = new MAX6675(kThermocoupleOneCsPin, kThermocoupleOneSoPin,
                                kThermocoupleOneSckPin);
  thermocoupleTwo = new MAX6675(kThermocoupleTwoCsPin, kThermocoupleTwoSoPin,
                                kThermocoupleTwoSckPin);
  thermocoupleOne->begin();
  thermocoupleTwo->begin();
  pinMode(kLevelTriggerPin, OUTPUT);
  digitalWrite(kLevelTriggerPin, LOW);
  pinMode(kLevelEchoPin, INPUT);
  pinMode(kFlowSensorPin, INPUT);  // GPIO34 is input-only; divider provides the level.
  attachInterrupt(digitalPinToInterrupt(kFlowSensorPin), onFlowPulse, FALLING);
  flowWindowStartedAt = millis();
  delay(250);  // MAX6675 conversion time after startup.
}

void ensureWiFi() {
  if (WiFi.status() == WL_CONNECTED) return;
  const unsigned long now = millis();
  if (now - lastReconnectAttemptAt < kReconnectIntervalMs) return;
  lastReconnectAttemptAt = now;
  WiFi.reconnect();
  Serial.println("Attempting Wi-Fi reconnect.");
}

void configureOtaClock() {
  // SNTP setup is asynchronous; OTA waits for a valid wall clock rather than
  // blocking telemetry or actuator safety while time is unavailable.
  configTime(0, 0, "time.google.com", "pool.ntp.org");
}

bool hasValidOtaTime() {
  time_t now = 0;
  time(&now);
  return now >= kEarliestValidTime;
}

bool fetchOtaManifest(OtaManifest &manifest) {
  WiFiClientSecure client;
  client.setCACert(kOtaRootCa);
  HTTPClient http;
  if (!http.begin(client, kOtaManifestUrl)) {
    Serial.println("OTA manifest connection initialization failed.");
    return false;
  }
  http.setTimeout(10000);
  http.addHeader("X-Device-Key", config.deviceKey);
  const int status = http.GET();
  const String body = status == 200 ? http.getString() : String();
  http.end();
  if (status != 200) {
    Serial.printf("OTA manifest request failed with HTTP status %d\n", status);
    return false;
  }
  manifest = parseOtaManifest(std::string(body.c_str()));
  if (!manifest.valid) Serial.println("OTA manifest is invalid; keeping current firmware.");
  return manifest.valid;
}

bool downloadAndInstallOta(const OtaManifest &manifest) {
  WiFiClientSecure client;
  client.setCACert(kOtaRootCa);
  HTTPClient http;
  if (!http.begin(client, manifest.url.c_str())) {
    Serial.println("OTA download connection initialization failed.");
    return false;
  }
  http.setTimeout(10000);
  const int status = http.GET();
  const int contentLength = http.getSize();
  if (status != 200 || contentLength <= 0) {
    Serial.printf("OTA download failed (HTTP %d, size %d).\n", status, contentLength);
    http.end();
    return false;
  }
  if (!Update.begin(static_cast<size_t>(contentLength), U_FLASH)) {
    Serial.printf("OTA could not reserve update space (error %u).\n", Update.getError());
    http.end();
    return false;
  }

  mbedtls_sha256_context sha;
  mbedtls_sha256_init(&sha);
  bool success = mbedtls_sha256_starts_ret(&sha, 0) == 0;
  WiFiClient *stream = http.getStreamPtr();
  uint8_t buffer[1024];
  int remaining = contentLength;
  while (success && remaining > 0) {
    const size_t requested = static_cast<size_t>(min(remaining, static_cast<int>(sizeof(buffer))));
    const size_t received = stream->readBytes(buffer, requested);
    if (received == 0 || mbedtls_sha256_update_ret(&sha, buffer, received) != 0 ||
        Update.write(buffer, received) != received) {
      success = false;
      break;
    }
    remaining -= static_cast<int>(received);
  }

  uint8_t digest[32];
  if (success) success = mbedtls_sha256_finish_ret(&sha, digest) == 0;
  mbedtls_sha256_free(&sha);
  http.end();
  char digestHex[65];
  for (size_t index = 0; index < sizeof(digest); ++index) {
    snprintf(digestHex + index * 2, 3, "%02x", digest[index]);
  }
  if (!success || remaining != 0 || manifest.sha256 != digestHex) {
    Serial.println("OTA download hash mismatch or stream failure; update aborted.");
    Update.abort();
    return false;
  }
  if (!Update.end()) {
    Serial.printf("OTA finalization failed (error %u).\n", Update.getError());
    return false;
  }
  Serial.printf("OTA version %s installed; rebooting.\n", manifest.version.c_str());
  ESP.restart();
  return true;  // Unreachable after restart; documents successful Update.end().
}

void checkForOtaUpdate() {
  if (WiFi.status() != WL_CONNECTED || config.deviceKey.isEmpty() || !hasValidOtaTime()) return;
  // Never block a commanded pump or queued telemetry retry for a firmware download.
  if (pump1On || pump2On || !pendingPayload.isEmpty()) return;

  OtaManifest manifest;
  if (!fetchOtaManifest(manifest)) return;
  if (!isNewerFirmwareVersion(THERMOMOLD_FIRMWARE_VERSION, manifest.version)) {
    Serial.println("OTA firmware is already current.");
    return;
  }
  Serial.printf("OTA update available: %s -> %s\n", THERMOMOLD_FIRMWARE_VERSION,
                manifest.version.c_str());
  downloadAndInstallOta(manifest);
}

bool postPayload(const String &payload) {
  if (config.endpoint.isEmpty()) {
    Serial.println("Telemetry endpoint is not configured; not posting.");
    return false;
  }
  if (WiFi.status() != WL_CONNECTED) return false;

  if (!hasHttpsScheme(std::string(config.endpoint.c_str()))) {
    Serial.println("Telemetry endpoint must use HTTPS; not posting.");
    return false;
  }

  HTTPClient http;
  const auto postWithClient = [&](WiFiClient &client) {
    if (!http.begin(client, config.endpoint)) {
      Serial.println("Could not initialize HTTP client.");
      return false;
    }
    http.setTimeout(10000);
    http.addHeader("Content-Type", "application/json");
    if (!config.deviceKey.isEmpty()) http.addHeader("X-Device-Key", config.deviceKey);
    const int status = http.POST(payload);
    const String body = (status >= 200 && status < 300) ? http.getString() : String();
    http.end();
    if (status < 200 || status >= 300) {
      Serial.printf("Telemetry POST failed with HTTP status %d\n", status);
      return false;
    }
    const PumpCommand command = parsePumpCommand(std::string(body.c_str()));
    applyCalibrationCommand(body);
    if (command.valid) {
      lastPumpCommandAt = millis();
      hasPumpCommand = true;
      applyPumps(command.pump1, command.pump2);
    } else {
      applyPumps(false, false);  // Backend without pump commands: stay safe.
    }
    return true;
  };

  WiFiClientSecure secureClient;
  // Render's certificate chain requires wall-clock synchronization on ESP32.
  // Encrypt transport immediately; replace with a pinned CA when NTP is available.
  secureClient.setInsecure();
  return postWithClient(secureClient);
}

void scheduleRetry() {
  nextRetryAt = millis() + retryDelayMs;
  retryDelayMs = min(retryDelayMs * 2, kMaximumRetryDelayMs);
}

unsigned long readLevelDistanceMm() {
  digitalWrite(kLevelTriggerPin, LOW);
  delayMicroseconds(2);
  digitalWrite(kLevelTriggerPin, HIGH);
  delayMicroseconds(10);
  digitalWrite(kLevelTriggerPin, LOW);
  return distanceMmFromEchoUs(pulseIn(kLevelEchoPin, HIGH, kLevelEchoTimeoutUs));
}

void reportTemperature() {
  if (thermocoupleOne->read() != 0 || thermocoupleTwo->read() != 0) {
    Serial.printf("MAX6675 sensor error (status %u, %u); measurement discarded.\n",
                  thermocoupleOne->getStatus(), thermocoupleTwo->getStatus());
    return;
  }
  const float thermocoupleOneC = thermocoupleOne->getCelsius();
  const float thermocoupleTwoC = thermocoupleTwo->getCelsius();
  if (!isValidTemperatureReading(thermocoupleOneC) || !isValidTemperatureReading(thermocoupleTwoC)) {
    Serial.println("MAX6675 produced an invalid temperature; measurement discarded.");
    return;
  }
  const unsigned long levelDistanceMm = readLevelDistanceMm();
  const bool levelAvailable = isValidLevelDistanceMm(levelDistanceMm);
  if (!levelAvailable) {
    Serial.println("AJ-SR04M unavailable; publishing telemetry without level.");
  }
  pendingPayload = buildFullTelemetryPayload(std::string(config.deviceId.c_str()),
                                             applyTemperatureCalibration(thermocoupleOneC, calibration.sensorOne),
                                             applyTemperatureCalibration(thermocoupleTwoC, calibration.sensorTwo),
                                             levelAvailable ? levelDistanceMm : 0, flowLpm,
                                             litersFromPulses(flowTotalPulses), pump1On,
                                             pump2On, thermocoupleOneC, thermocoupleTwoC,
                                             calibration.revision).c_str();
  if (postPayload(pendingPayload)) {
    Serial.printf("Telemetry posted: %.2f C, %.2f C, %s, %.2f L/min\n", thermocoupleOneC,
                  thermocoupleTwoC, levelAvailable ? (String(levelDistanceMm) + " mm").c_str() : "level unavailable",
                  flowLpm);
    pendingPayload = "";
    retryDelayMs = kInitialRetryDelayMs;
  } else {
    scheduleRetry();
  }
}
}  // namespace

void setup() {
  configurePumpsOff();
  Serial.begin(115200);
  initializeCalibration();
  // Format a blank/corrupted LittleFS partition so portal settings persist after reset.
  if (!LittleFS.begin(true)) Serial.println("LittleFS unavailable; settings will not persist.");
  loadConfig();
  provisionWiFiAndSettings();
  configureOtaClock();
  configureSensor();
  nextReportAt = millis();
  nextOtaCheckAt = millis();
}

void loop() {
  ensureWiFi();
  updateFlow();
  enforcePumpFailSafe();
  const unsigned long now = millis();
  if (now >= nextOtaCheckAt) {
    checkForOtaUpdate();
    // NTP synchronization starts asynchronously. Retry soon until TLS has a valid clock;
    // once valid, retain the normal 15-minute polling interval.
    nextOtaCheckAt = now + (hasValidOtaTime() ? kOtaCheckIntervalMs : 30000UL);
  }
  if (!pendingPayload.isEmpty() && now >= nextRetryAt) {
    if (postPayload(pendingPayload)) {
      pendingPayload = "";
      retryDelayMs = kInitialRetryDelayMs;
    } else {
      scheduleRetry();
    }
  }
  if (pendingPayload.isEmpty() && now >= nextReportAt) {
    nextReportAt = now + minimumTelemetryIntervalMs();
    reportTemperature();
  }
}

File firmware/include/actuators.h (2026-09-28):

#pragma once

#include <cstdint>
#include <string>

// ZJ-S201 (YF-S201 family): pulse frequency Hz = 7.5 * flow L/min.
// Calibrate this constant against a measured volume if readings drift.
constexpr float kFlowPulsesPerSecondPerLpm = 7.5f;
// Default pump command timeout: no successful backend response for this long -> pumps OFF.
constexpr unsigned long kPumpCommandTimeoutMs = 3000;

inline float flowLitersPerMinute(unsigned long pulses, unsigned long windowMs) {
  if (windowMs == 0) return 0.0f;
  const float pulsesPerSecond = (pulses * 1000.0f) / windowMs;
  return pulsesPerSecond / kFlowPulsesPerSecondPerLpm;
}

inline float litersFromPulses(unsigned long pulses) {
  return pulses / (kFlowPulsesPerSecondPerLpm * 60.0f);
}

// millis() is 32-bit on ESP32; fixed-width unsigned subtraction stays correct across rollover.
inline bool pumpCommandExpired(uint32_t lastCommandAtMs, uint32_t nowMs, uint32_t timeoutMs) {
  return static_cast<uint32_t>(nowMs - lastCommandAtMs) > timeoutMs;
}

struct PumpCommand {
  bool valid = false;
  bool pump1 = false;
  bool pump2 = false;
};

namespace pump_command_detail {
// Returns 1 for true, 0 for false, -1 when the key is missing or not a boolean.
inline int readBool(const std::string &object, const std::string &key) {
  const std::string needle = "\"" + key + "\":";
  const size_t at = object.find(needle);
  if (at == std::string::npos) return -1;
  const size_t valueAt = at + needle.size();
  if (object.compare(valueAt, 4, "true") == 0) return 1;
  if (object.compare(valueAt, 5, "false") == 0) return 0;
  return -1;
}
}  // namespace pump_command_detail

// Parses {"commands":{"pumps":{"pump1":bool,"pump2":bool}}} from the backend response.
// Any missing or malformed field yields an invalid, all-off command (fail-safe).
inline PumpCommand parsePumpCommand(const std::string &body) {
  PumpCommand command;
  const std::string marker = "\"pumps\":{";
  const size_t start = body.find(marker);
  if (start == std::string::npos) return command;
  const size_t end = body.find('}', start + marker.size());
  if (end == std::string::npos) return command;

  const std::string object = body.substr(start + marker.size(), end - start - marker.size());
  const int pump1 = pump_command_detail::readBool(object, "pump1");
  const int pump2 = pump_command_detail::readBool(object, "pump2");
  if (pump1 < 0 || pump2 < 0) return command;

  command.valid = true;
  command.pump1 = pump1 == 1;
  command.pump2 = pump2 == 1;
  return command;
}

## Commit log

2026-09-10 feat: add ESP32 MAX6675 telemetry
2026-09-17 feat: publish multi-sensor telemetry
2026-09-17 fix: format settings storage after reset
    [main.cpp]
2026-09-28 feat: manual pump control, ZJ-S201 flow telemetry and wiring README
    [thermomold.kicad_sch]
2026-10-01 chore: use reliable ESP32 upload speed
2026-10-01 fix: publish telemetry when optional level sensor is unavailable
    [main.cpp]
2026-10-01 fix: retry OTA check while clock synchronizes
    [main.cpp]
2026-10-01 feat: add live session charts for sensor readings
2026-10-08 feat: add public two-point MAX6675 calibration
2026-10-08 fix: guide two-step thermocouple calibration
2026-10-15 fix: stabilize ESP32 Wi-Fi telemetry
2026-10-22 feat: firmware 0.1.5 with MAX6675 diagnostics
    - firmware: bump to 0.1.5; include diagnostics.max6675Status [s1,s2] in fault telemetry
    - server: validate and pass through optional diagnostics.max6675Status (two ints 0..255)
    - server: test accepted/rejected diagnostics and payloads without diagnostics
    - client: show per-thermocouple MAX6675 warning on the real sensor page
2026-10-22 fix: firmware 0.1.6 filters false flow pulses and noisy level readings
    - flow: ISR rejects edges < 2 ms after the previous edge (30 L/min = 4.4 ms period);
    a window counts only if >= 1 L/min, spread over the window and confirmed by the
    next window, so bursts never reach totalLiters
    - level: 20 us trigger, 5 pings 70 ms apart (one per loop pass), median of pings
    within the 20 cm..8 m datasheet range, unavailable if fewer than 3 are valid
    - native tests for both filters; OTA manifest/bin 0.1.6
2026-10-22 docs: document 0.1.6 flow/level filters and MAX6675 diagnostics
2026-10-22 fix: firmware 0.1.7 reads MAX6675 with datasheet timing
    The robtillaart/MAX6675 zero-delay software SPI read MAX6675 #1 as ~110 C at
    room temperature. The isolated diagnostic in tools/max6675_diag shows both
    library variants wrong on #1 and the ~100 kHz hand bit-bang correct on both
    (24.0 / 24.2 C, no invalid frames).
2026-10-22 fix: firmware 0.1.8 reports an all-zero MAX6675 frame as no communication
    On the external supply MAX6675 #1 returned 0.00 C with status OK: an SO line held
    low decodes as a plausible 0 C. Treat 0x0000 as no communication (status 129),
    re-assert the bus pin modes on every read, and publish the raw frames in
    diagnostics.max6675Raw on every sample so the next field fault is visible.
2026-10-22 feat: firmware 0.1.9 publishes the raw AJ-SR04M pings
    The level reads unavailable on site. Publish the five pings of the last burst in
    diagnostics.levelRawMm (0 = no echo) so a silent sensor can be told apart from
    echoes inside the 20 cm blind zone or beyond 8 m without a USB connection.
2026-10-22 fix: keep relay command alive across telemetry interval
2026-10-22 fix: apply commands.pumps instead of stale telemetry state
2026-11-02 feat: integrated USB raw temperature and flow diagnostics
2026-11-02 fix: preserve legitimate MAX6675 zero-degree frames
2026-11-02 test: compare hardware SPI and record pending ice calibration point
2026-11-02 feat: apply measured two-point temperature calibration through local USB
2026-11-02 feat: add safe known-volume flow calibration panel and session API
2026-11-02 feat: publish cumulative raw flow counters for volume calibration
2026-11-02 feat: tank level percent and approved three-trial raw flow calibration
2026-11-02 fix: tank empty at 333 mm and full at 270 mm
2026-11-02 fix: full tank reference is 280 mm
2026-11-02 fix: full tank reference is 293 mm
